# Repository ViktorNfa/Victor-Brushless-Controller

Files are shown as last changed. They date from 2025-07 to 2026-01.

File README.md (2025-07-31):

# Victor Brushless Controller (VBC)

This repository contains the **firmware** and **KiCad hardware design files** for the **Victor Brushless Controller (VBC)**, a custom BLDC motor controller inspired by the [Dagor Brushless Controller](https://github.com/byDagor/Dagor-Brushless-Controller).

## Overview

VBC is a compact, ESP32-based brushless controller designed for use in robotic and actuator applications. It integrates key hardware components to support precise control of brushless motors with wired or wireless communication.

The controller supports three operation modes:
- **Position control**.
- **Velocity control**.
- **Torque control**.

In both voltage- and current-control modes. It is compatible with the [SimpleFOC](https://docs.simplefoc.com/) library and can be programmed using the Arduino IDE.

## Features

- ESP32-based microcontroller.
- Onboard 3-phase MOSFET driver and half-bridges.
- Integrated 14-bit magnetic encoder.
- Current sensing resistors.
- Onboard temperature sensor.
- Custom firmware tailored for SimpleFOC.
- KiCad schematics and PCB layout included.

## Hardware Specs

| Specification | Value |
|---|---|
| Board Dimensions | ~44 x 44 mm |
| Supply Voltage | 5 – 24 V |
| Peak RMS Current | up to 40 A |
| Magnetic Sensor Resolution| 14 bits |
| Temperature Range | -10°C to 120°C |

> 🧪 Note: This is a **custom derivative project**, still under development. Use with caution and test thoroughly.

## Repository Structure

- `VBC-SW/` – Source code for the controller (Arduino + SimpleFOC).
- `VBC-HW/` – KiCad project files for PCB schematics and layout.
- `KiCad_libraries/` – Custom footprints & symbols needed for KiCad.

## Acknowledgements

Based on the fantastic work by [@byDagor](https://github.com/byDagor) and the [Dagor Brushless Controller](https://docs.dagor.dev/).

## License

To decide – see `...` file for details.

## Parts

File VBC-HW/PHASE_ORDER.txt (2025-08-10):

Dagor's connected Motor Phase Terminal C to DRV phase and amplifiers pins A and 1, respectively. 
Similarly, for Motor Phase Terminal A to DRV phase and amplifiers pins C and 3, respectively.

Not sure why he did this, maybe from his current motor setup or an error. 
It doesn't really affect anything as long as the BLDCDriver construct in the code is properly called reverted.

For my KiCad version I correctly connected A to A and C to C so no need to switch on the code.

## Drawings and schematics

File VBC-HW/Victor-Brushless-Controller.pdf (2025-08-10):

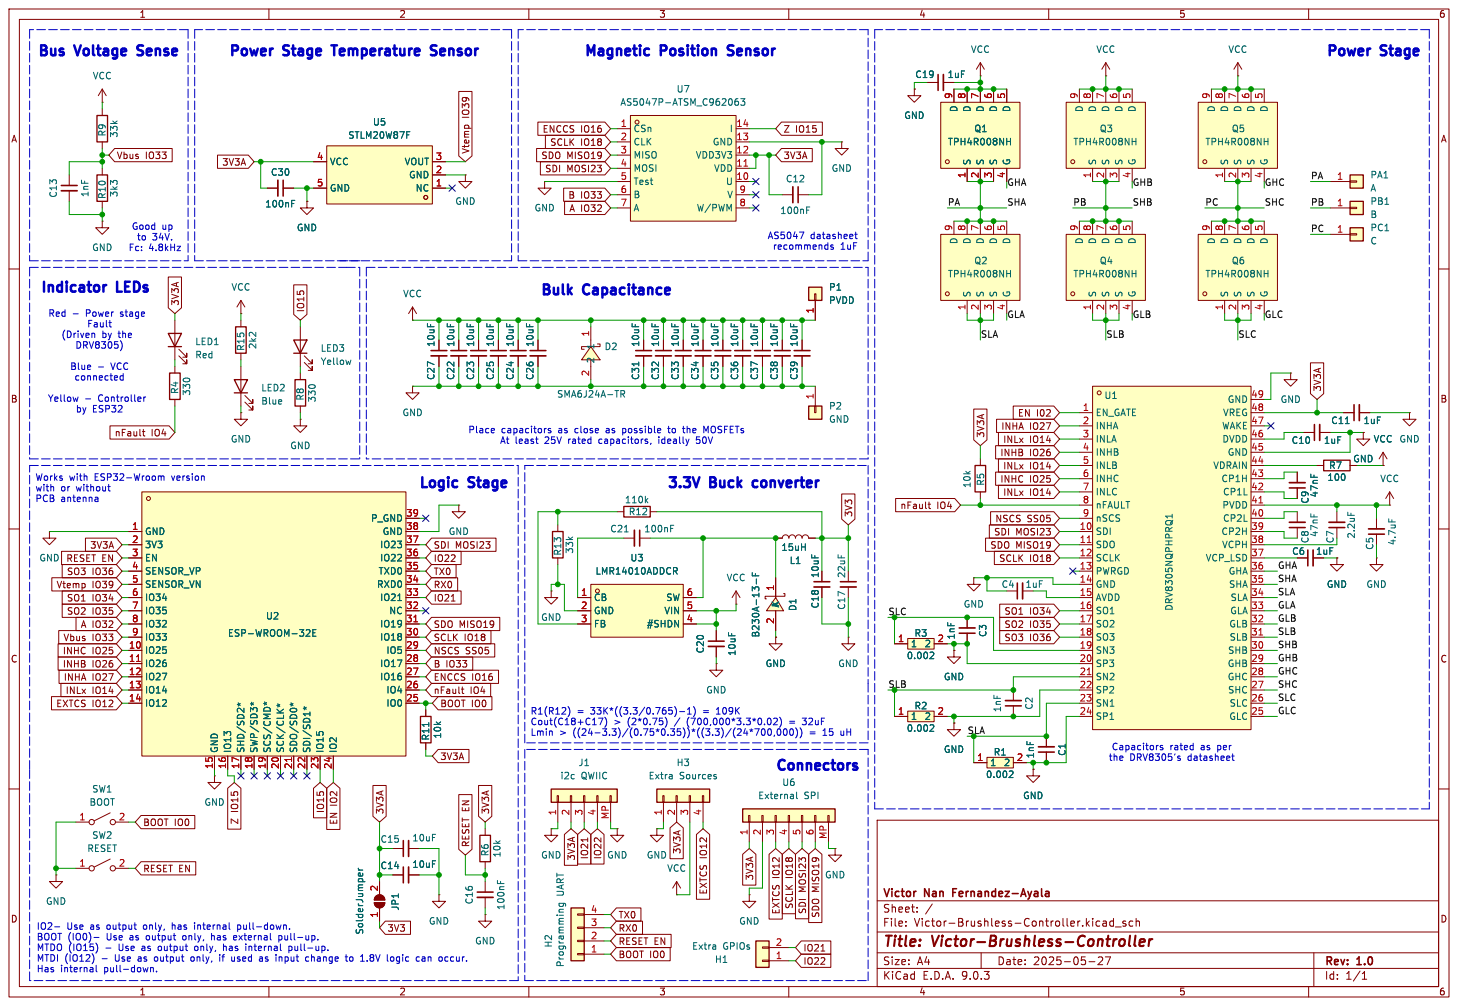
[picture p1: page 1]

9 W/PWM 8 U7 AS5047P-ATSM_C962063
CSn 1 CLK 2 MISO 3 MOSI 4 Test 5 B

connected Yellow - Controller by ESP32

2 D1 B230A-13-F C10 1uF GND GND GND C20 10uF GND GND

2 C20 10uF GND JP1 SolderJumper 1 2 U2 ESP-WROOM-32E GND 1

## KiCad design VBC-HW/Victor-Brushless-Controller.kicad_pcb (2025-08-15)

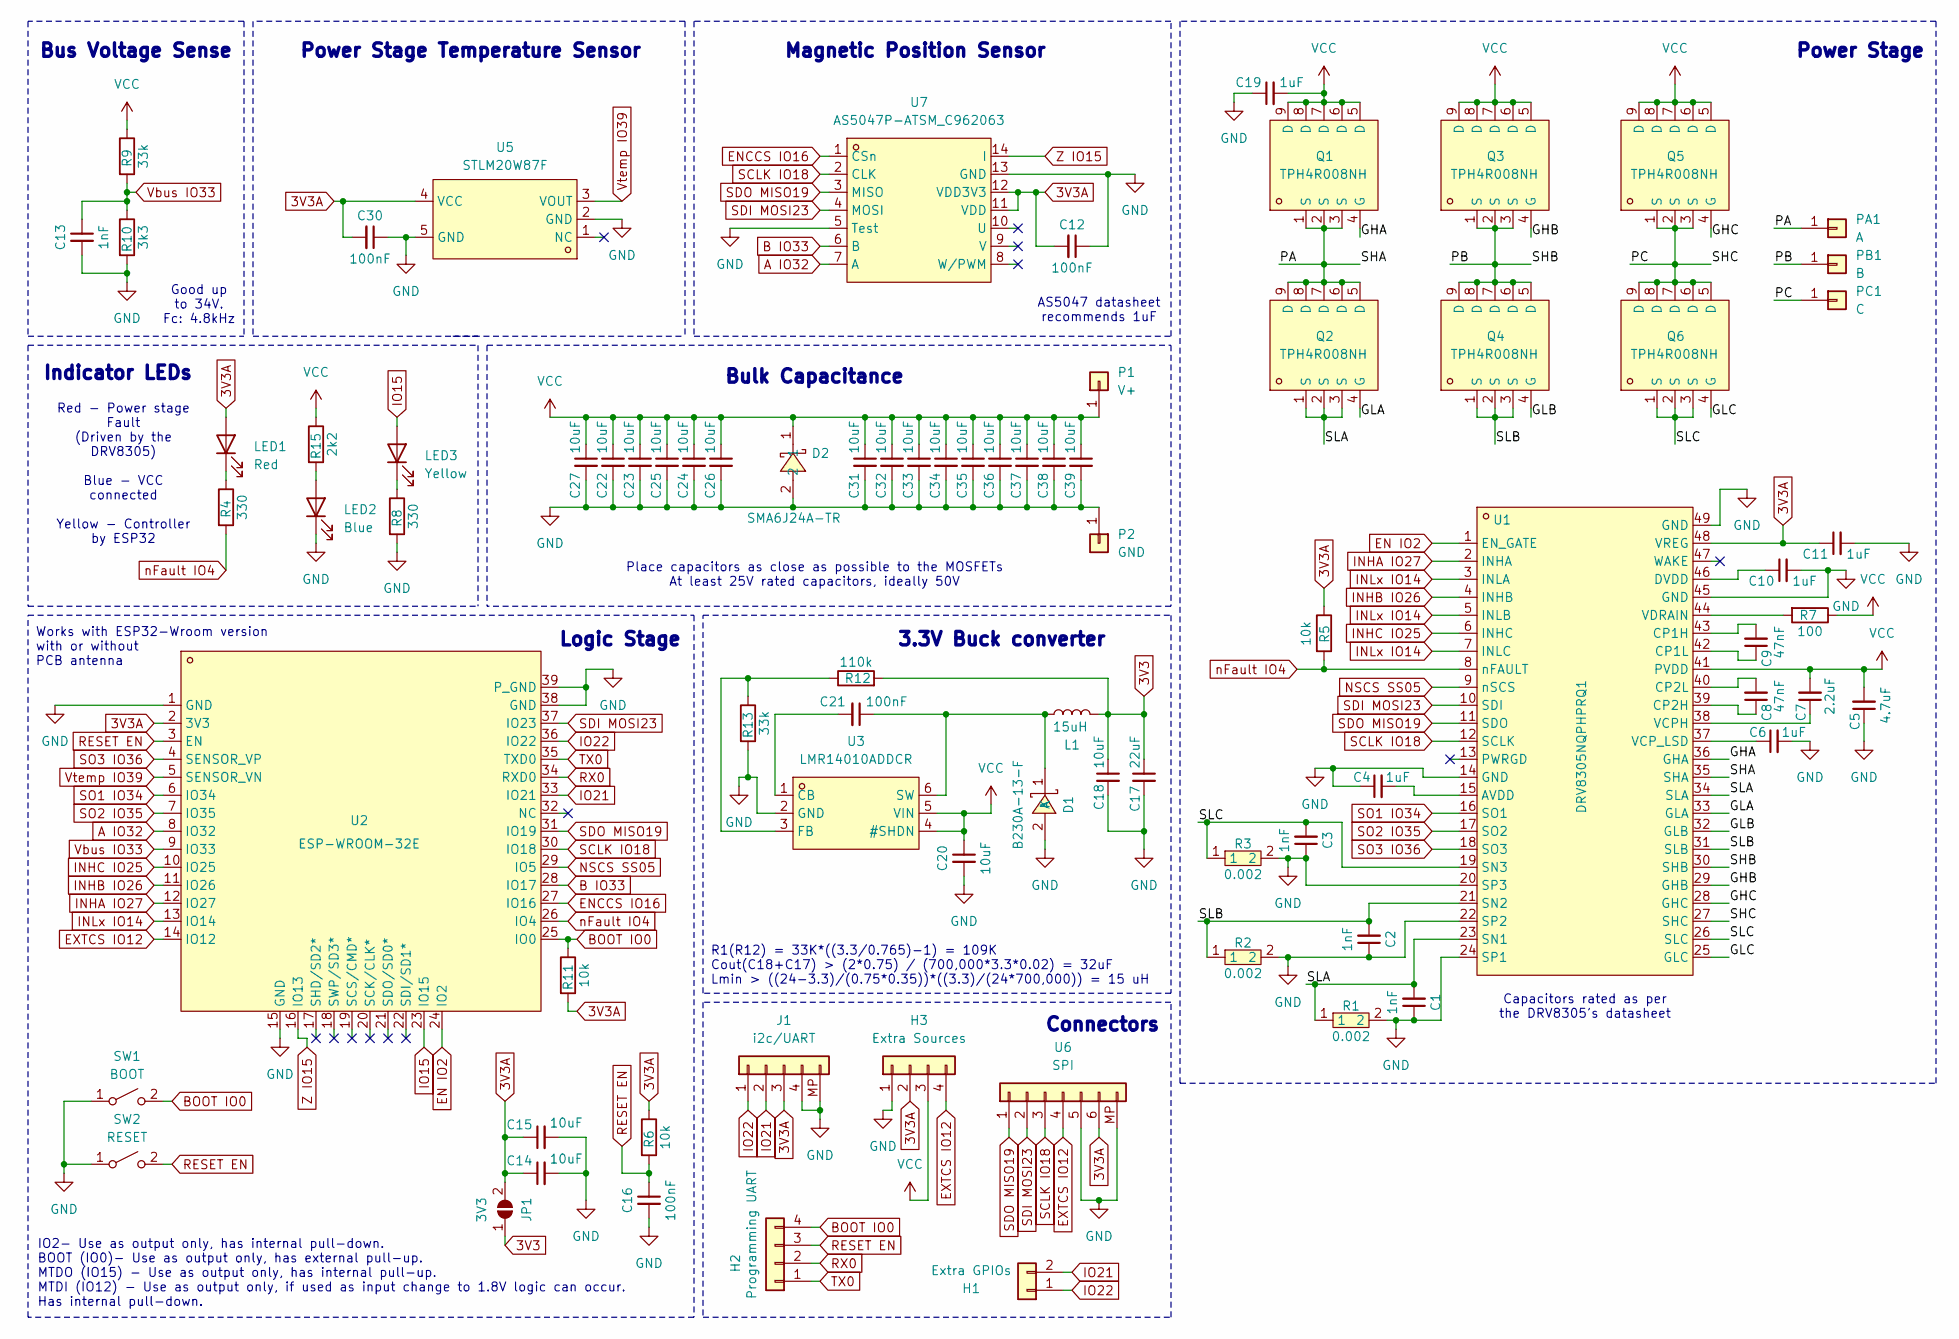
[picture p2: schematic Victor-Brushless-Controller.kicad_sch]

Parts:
C1, C2, C3, C13: 1nF; 0402B102K500NT
C4, C6, C10, C11: 1uF; CL05A105KA5NQNC
C5: 4.7uF; 1206B475K500NT
C7: 2.2uF; CL31B225KBHNNNE
C8: 47nF; CL21B473KCFNNNE
C9: 47nF; CL10B473KB8NNNC
C12, C16, C21, C30: 100nF; CL05B104KO5NNNC
C14: 10uF; CL05A106MQ5NUNC
C15: 10uF; CL05B104KO5NNNC
C17: 22uF; CL10A226MQ8NRNC
C18: 10uF; CL10A106MA8NRNC
C19: 1uF; CL10A105KB8NNNC
C20, C22, C23, C24, C25, C26, C27, C31, C32, C33, C34, C35, C36, C39: 10uF; GRM21BR61H106KE43L
C37, C38: 10uF; 1206X106M500NT
D1: B230A-13-F; LCSC Part C12889
D2: SMA6J24A-TR; SMA6J24A; LCSC Part C1975444
H1: Extra GPIOs; PinHeader_1x02_P2.54mm_Vertical
H2: Programming UART; PinHeader_1x04_P2.54mm_Vertical
H3: Extra Sources; PinHeader_1x04_P2.54mm_Vertical
J1: i2c/UART; JST_GH_BM04B-GHS-TBT_1x04-1MP_P1.25mm_Vertical
JP1: 3V3; SolderJumper-2_P1.3mm_Open_Pad1.0x1.5mm
L1: 15uH; PIS3D18P-150M-T
LED1: Red; KT-0603R
LED2: Blue; 19-217
LED3: Yellow; 19-213
P1: V+; Power_Connector
P2: GND; Power_Connector
PA1: A; BLDC_Connector
PB1: B; BLDC_Connector
PC1: C; BLDC_Connector
Q1, Q2, Q3, Q4, Q5, Q6: TPH4R008NH; TPH4R008NH,L1Q(M; LCSC Part C396039
R1, R2, R3: 0.002; CUM2512-24FR002; LCSC Part C323765
R4, R8: 330; 0402WGF3300TCE
R5, R6, R11: 10k; 0402WGF1002TCE
R7: 100; 0402WGF1000TCE
R9, R13: 33k; 0402WGF3302TCE
R10: 3k3; 0402WGF3301TCE
R12: 110k; RC0402FR-07110KL
R15: 2k2; 0402WGF2201TCE
SW1: BOOT; TS342A2P-WZ
SW2: RESET; TS342A2P-WZ
U1: DRV8305NQPHPRQ1; LCSC Part C701780
U2: ESP-WROOM-32E; LCSC Part C19949066
U3: LMR14010ADDCR; LCSC Part C388174
U5: STLM20W87F; LCSC Part C129796
U6: SPI; JST_GH_BM06B-GHS-TBT_1x06-1MP_P1.25mm_Vertical
U7: AS5047P-ATSM_C962063; AS5047P-ATSM; LCSC Part C962063

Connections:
3V3: C17.1, C18.1, JP1.1 (A), L1.2, R12.2
3V3A: C11.1, C12.2, C14.1, C15.1, C30.2, H3.2, J1.3, JP1.2 (B), LED1.2 (A), R5.1, R6.1, R11.2, U1.48 (VREG), U2.2 (3V3), U5.4 (VCC), U6.6, U7.11 (VDD), U7.12 (VDD3V3)
/GHA: Q1.4 (G), U1.36 (GHA)
/GHB: Q3.4 (G), U1.29 (GHB)
/GHC: Q5.4 (G), U1.28 (GHC)
/GLA: Q2.4 (G), U1.33 (GLA)
/GLB: Q4.4 (G), U1.32 (GLB)
/GLC: Q6.4 (G), U1.25 (GLC)
/PA: PA1.1, Q1.1 (S), Q1.2 (S), Q1.3 (S), Q2.5 (D), Q2.6 (D), Q2.7 (D), Q2.8 (D), Q2.9 (D), U1.35 (SHA)
/PB: PB1.1, Q3.1 (S), Q3.2 (S), Q3.3 (S), Q4.5 (D), Q4.6 (D), Q4.7 (D), Q4.8 (D), Q4.9 (D), U1.30 (SHB)
/PC: PC1.1, Q5.1 (S), Q5.2 (S), Q5.3 (S), Q6.5 (D), Q6.6 (D), Q6.7 (D), Q6.8 (D), Q6.9 (D), U1.27 (SHC)
/SLA: C1.2, Q2.1 (S), Q2.2 (S), Q2.3 (S), R1.1, U1.23 (SN1), U1.34 (SLA)
/SLB: C2.2, Q4.1 (S), Q4.2 (S), Q4.3 (S), R2.1, U1.21 (SN2), U1.31 (SLB)
/SLC: C3.2, Q6.1 (S), Q6.2 (S), Q6.3 (S), R3.1, U1.19 (SN3), U1.26 (SLC)
A IO32: U2.8 (IO32), U7.7 (A)
B IO33: U2.28 (IO17), U7.6 (B)
BOOT IO0: H2.4, R11.1, SW1.2 (B), U2.25 (IO0)
EN IO2: U1.1 (EN_GATE), U2.24 (IO2)
ENCCS IO16: U2.27 (IO16), U7.1 (CSn)
EXTCS IO12: H3.4, U2.14 (IO12), U6.4
GND: C1.1, C2.1, C3.1, C4.1, C5.1, C6.2, C10.2, C11.2, C12.1, C13.2, C14.2, C15.2, C16.2, C17.2, C18.2, C19.1, C20.2, C22.2, C23.2, C24.2, C25.2, C26.2, C27.2, C30.1, C31.2, C32.2, C33.2, C34.2, C35.2, C36.2, C37.2, C38.2, C39.2, D1.2 (A), D2.2, H3.1, J1.4, J1.MP, LED2.1 (K), P2.1, R1.2, R2.2, R3.2, R8.2, R10.2, R13.2, SW1.1 (A), SW2.1 (A), U1.14 (GND), U1.20 (SP3), U1.22 (SP2), U1.24 (SP1), U1.45 (GND), U1.49 (GND), U2.1 (GND), U2.15 (GND), U2.38 (GND), U2.39 (P_GND), U3.2 (GND), U5.2 (GND), U5.5 (GND), U6.5, U6.MP, U7.5 (Test), U7.13 (GND)
INHA IO27: U1.2 (INHA), U2.12 (IO27)
INHB IO26: U1.4 (INHB), U2.11 (IO26)
INHC IO25: U1.6 (INHC), U2.10 (IO25)
INLx IO14: U1.3 (INLA), U1.5 (INLB), U1.7 (INLC), U2.13 (IO14)
IO15: LED3.2 (A), U2.23 (IO15)
IO21: H1.2, J1.2, U2.33 (IO21)
IO22: H1.1, J1.1, U2.36 (IO22)
NSCS SS05: U1.9 (nSCS), U2.29 (IO5)
unnamed: C21.1, D1.1 (K), L1.1, U3.6 (SW)
unnamed: LED1.1 (K), R4.1
unnamed: LED2.2 (A), R15.2
unnamed: LED3.1 (K), R8.1
unnamed: C4.2, U1.15 (AVDD)
unnamed: C9.2, U1.43 (CP1H)
unnamed: C9.1, U1.42 (CP1L)
unnamed: C8.1, U1.39 (CP2H)
unnamed: C8.2, U1.40 (CP2L)
unnamed: C10.1, U1.46 (DVDD)
unnamed: C7.1, U1.38 (VCPH)
unnamed: C6.1, U1.37 (VCP_LSD)
unnamed: R7.2, U1.44 (VDRAIN)
unnamed: C21.2, U3.1 (CB)
unnamed: R12.1, R13.1, U3.3 (FB)
RESET EN: C16.1, H2.3, R6.2, SW2.2 (B), U2.3 (EN)
RX0: H2.2, U2.34 (RXD0)
SCLK IO18: U1.12 (SCLK), U2.30 (IO18), U6.3, U7.2 (CLK)
SDI MOSI23: U1.10 (SDI), U2.37 (IO23), U6.2, U7.4 (MOSI)
SDO MISO19: U1.11 (SDO), U2.31 (IO19), U6.1, U7.3 (MISO)
SO1 IO34: U1.16 (SO1), U2.6 (IO34)
SO2 IO35: U1.17 (SO2), U2.7 (IO35)
SO3 IO36: U1.18 (SO3), U2.4 (SENSOR_VP)
TX0: H2.1, U2.35 (TXD0)
VCC: C5.2, C7.2, C19.2, C20.1, C22.1, C23.1, C24.1, C25.1, C26.1, C27.1, C31.1, C32.1, C33.1, C34.1, C35.1, C36.1, C37.1, C38.1, C39.1, D2.1, H3.3, P1.1, Q1.5 (D), Q1.6 (D), Q1.7 (D), Q1.8 (D), Q1.9 (D), Q3.5 (D), Q3.6 (D), Q3.7 (D), Q3.8 (D), Q3.9 (D), Q5.5 (D), Q5.6 (D), Q5.7 (D), Q5.8 (D), Q5.9 (D), R7.1, R9.1, R15.1, U1.41 (PVDD), U3.4 (#SHDN), U3.5 (VIN)
Vbus IO33: C13.1, R9.2, R10.1, U2.9 (IO33)
Vtemp IO39: U2.5 (SENSOR_VN), U5.3 (VOUT)
Z IO15: U2.16 (IO13), U7.14 (I)
nFault IO4: R4.2, R5.2, U1.8 (nFAULT), U2.26 (IO4)

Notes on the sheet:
3.3V Buck converter
Red - Power stage Fault (Driven by the DRV8305) Blue - VCC connected Yellow - Controller by ESP32
Power Stage Temperature Sensor
Capacitors rated as per the DRV8305's datasheet
Indicator LEDs
Power Stage
AS5047 datasheet recommends 1uF
Place capacitors as close as possible to the MOSFETs At least 25V rated capacitors, ideally 50V
Works with ESP32-Wroom version with or without PCB antenna
Bus Voltage Sense
Good up to 34V. Fc: 4.8kHz
Bulk Capacitance
Connectors
Magnetic Position Sensor
R1(R12) = 33K*((3.3/0.765)-1) = 109K Cout(C18+C17) > (2*0.75) / (700,000*3.3*0.02) = 32uF Lmin > ((24-3.3)/(0.75*0.35))*((3.3)/(24*700,000)) = 15 uH
IO2- Use as output only, has internal pull-down. BOOT (IO0)- Use as output only, has external pull-up. MTDO (IO15) - Use as output only, has internal pull-up. MTDI (IO12) - Use as output only, if used as input change to 1.8V logic can occur. Has internal pull-down.
Logic Stage

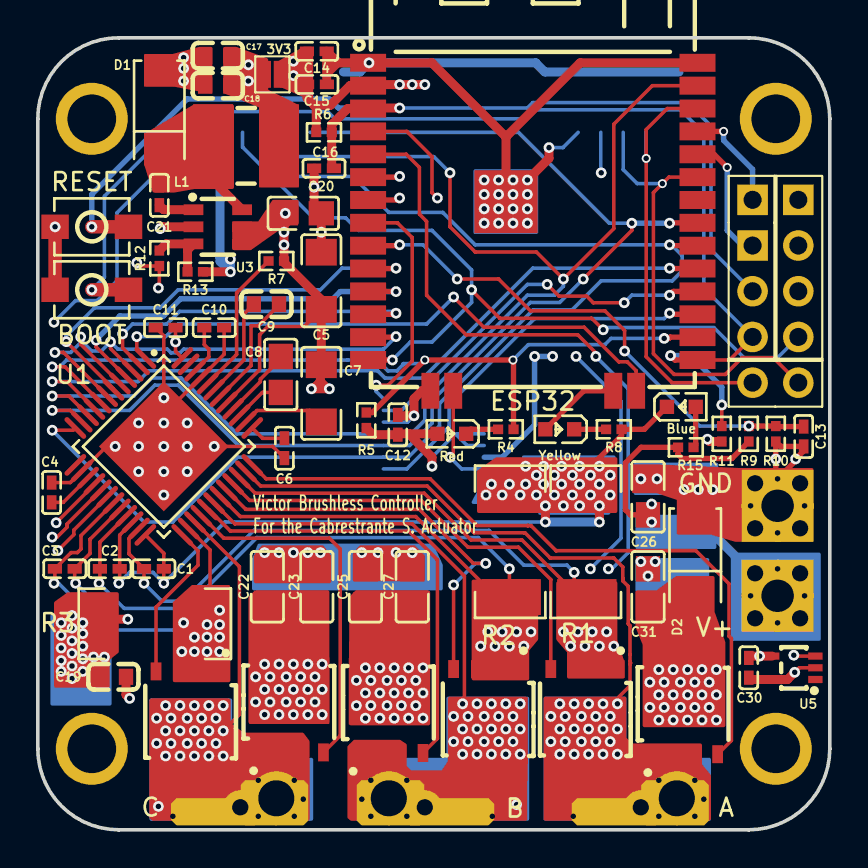
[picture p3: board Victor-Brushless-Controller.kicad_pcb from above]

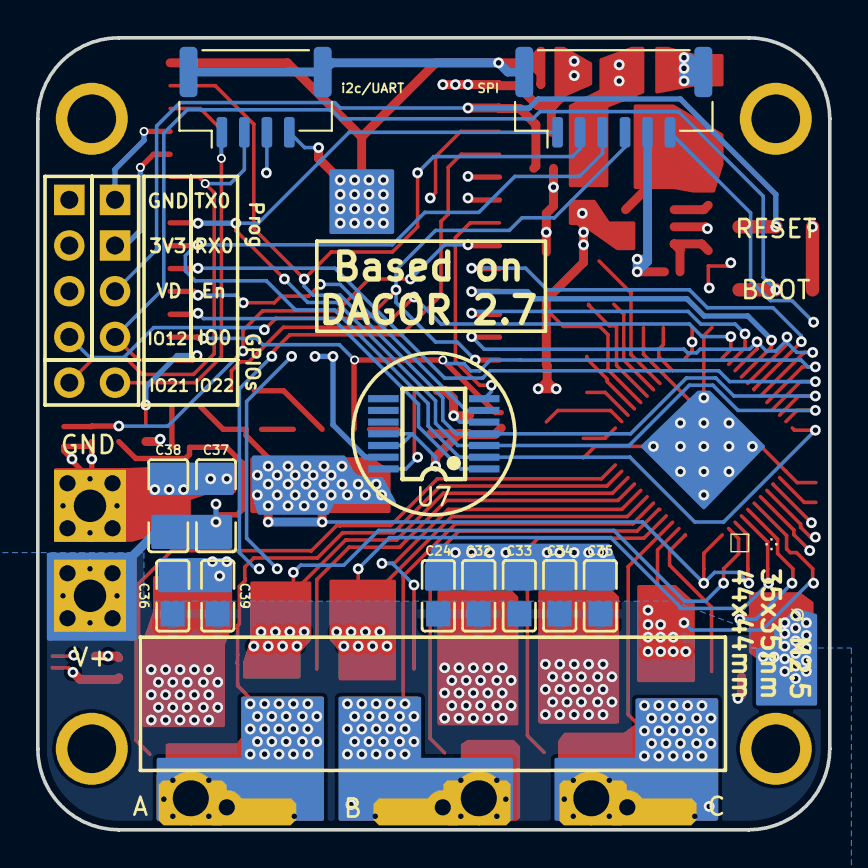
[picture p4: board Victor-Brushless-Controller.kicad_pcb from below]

Board: 4 copper layers, 44.0 x 44.0 mm, 81 parts (13 on the bottom side), 58 nets.

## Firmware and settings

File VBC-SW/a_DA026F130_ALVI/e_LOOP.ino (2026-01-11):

//###########################################
//         SUPER LOOP - Core 1
//###########################################

// Do NOT add delay inside the loop void.

void loop() {

  if (state_machine < DRV_WARNING){
     // These functions have to run as fast as possible
    motor.loopFOC();
    autoSweepUpdate();
    motor.move();
    activeComp();

    if (print_foc_freq) printFOCfreq();

    #ifdef DEBUG_ADAPTER
      command.run();
      //motor.monitor();
    #endif 

  } else{

    static bool error_printed = false;

    if (!error_printed){
      error_printed = true;
      Serial.print("Dagor: Error -> State Machine: ");
      Serial.println(state_machine);
    }
    vTaskDelay(1 / portTICK_PERIOD_MS);

  }

}

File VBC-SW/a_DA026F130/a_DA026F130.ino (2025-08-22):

//####################################################################################
//                         Dagor Controller Alpha Firmware
//                   Compatible with Alpha versions 2.4 and above
//            [Modified by Victor Nan Fernandez-Ayala for the VBC board]
//####################################################################################

#include <SimpleFOC.h>
#define FW_VERSION "1.4.0"

// The firmware is separated into 7 tabs (a - g), make sure all files are stored in the folder with the same name as tab a_DAXXXFXXX.
// This tab cointains the parameters to customize the controller. Learn more at https://docs.dagor.dev/

// Refactoring to use both cores leveraging freeRTOS
//TODO:
//    Stall detection algorithm
//    Finish RS-485-based protocol, directional comms working
//    Virtual Walls algo
//    Detect DRV warnings vs. errors
//    Make nicer out of bounds behavior
//    Finish implementing state machine
//    Change "H" homing command to accept home as arbitrary number or current position

//#######_USER SET-UP PARAMETERS_#######
#define ACT_ID 100                                              // Actuator ID, used for ESP-NOW or RS-485 comms
const int pp = 20;                                              // BLDC motor number of pole pairs
const float phaseRes = 0.186;                                   // Phase winding resistance [ohms]
const float amp_limit = 7.0;                                   // IQ current limit [amps] - requires trueTorque mode                           
const float alignStrength = 0.1;                                // Percentage of available bus voltage used to calibrate the sensor on start-up
MotionControlType controlType = MotionControlType::torque;      // control types: angle, velocity, torque


// Below are the control loops start-up parameters, to obtain the desired response out of the  
// controller they need to be tuned. These parameters can be tuned via the SimpleFOC's "Commander"  
// interface, which is based on ASCII character command ids. There are two types of commands, a 
// fetch and a set. A fetch command will have the following structure:
//                               motor ID ->  MLC <- Current
//                                             ^
//                                             |
//                                           Limits
//
// These commands can be sent through the Serial Monitor, make sure to set the baud rate to 115200 and 
// "Newline". To the right of the variables below there are the characters that would be used to fetch
// or set each individual parameter. There is a cheat-sheet of the commands at the bottom of this tab.
// Make sure to write the final values of the parameters after tuning to update the firmware and 
// upload it again.


//#######_START-UP CONTROLLER PARAMETERS_#######                                         //  Commander IDs:
const float cp = 0.5;                     // QD current loops PROPORTONAL gain value            - MQP & MDP
const float ci = 20.0;                    // QD current loops INTEGRAL gain value                - MQI & MDI
const float cd = 0.0;                     // QD current loops DERIVATIVE gain value             - MQD & MDD
const float lpQDFilter = 0.01;            // QD current loops measurement low-pass filter       - QF & DF

const float vp = 0.3;                     // Velocity control loop PROPORTIONAL gain value      - VP
const float vi = 2.0;                     // Velocity control loop INTEGRAL gain value          - VI
const float vd = 0.0;                     // Velocity control loop DERIVATIVE gain value        - VD
const float lpVelFilter = 0.01;           // Velocity measurement low-pass filter               - VF
const float velocity_limit = 20;          // Velocity limit [rad/s]                             - LV

const float ap = 30.0;                    // Position control loop PROPORTIONAL gain value      - AP
const float ai = 0.0;                     // Position control loop INTEGRAL gain value          - AI
const float ad = 0.0;                     // Position control loop DERIVATIVE gain value        - AD
const float lpPosFilter = 0.001;          // Position measurment low-pass filter                - AF
const float voltageRamp = 2000;           // Change in voltage allowed [Volts per sec]          - VR


//########_ADVANCED PARAMETERS_##########
#define CURRENT_SENSE                     // Define if using current sense, difference between current control or voltage control mode.  
const bool trueTorque = true;             // Even if using current sense, torque mode can be voltage torque mode if set to false
const bool print_currents = true;         // Monitor currents through the serial terminal 
const bool print_dq_currents = true;      // true-> print DQ currents, false -> print phase currents

#define MONITOR_TEMP                      // define -> monitor and evaluate controllers temperature, parameters below ignored if undef
const bool print_temp = false;            // Monitor temperature through the serial terminal
const int maxTemp = 75;                   // Maximum operating temperature of the power-stage [°C]
const float overTempTime = 1.0;           // Time to elapse in an over-temperature state to disable the controller [seconds]

#undef MONITOR_BUS_VOLTAGE                // Monitor bus voltage, automatically adjust to the lowering battery voltage
const bool print_bus_voltage = false;     // Monitor the bus voltage through the serial terminal
const float voltageOverride = 22.0;       // Voltage of your power source [Volts], overrides source voltage if MONITOR_BUS_VOLTAGE is undefined

#define MONITOR_ROTOR                     // Monitor rotor position and velocity, parameters below ignored if undef
const bool print_rotor_data = false;      // Monitor roto's position and velocity (respectively) through the serial terminal
const float max_rotor_position = 10000;   // Max position [rad] the rotor is allowed to spin to; above this value, motor will freewheel 
const float min_rotor_position = -10000;  // Min position [rad] the rotor is allowed to spin to; below this value, motor will freewheel 

#undef SKIP_SENSOR_CALIB                  // Skip the position sensor calibration on start-up
                                          // electric angle offset and natural direction printed on start-up
const float zero_elec_angle = 0.00;       // Printed as: "MOT: Zero elec. angle: X.XX"
Direction nat_dir = Direction::CW;        // Can be either CW or CCW

#define DEBUG_ADAPTER                     // define if using USB programming/debug adapter (usb to ttl connected to board)
                                          // Recommended to disable when adapter will not be connected to computer
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

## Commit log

2025-03-29 Added KiCad libraries
    [Victor-Brushless-Controller.kicad_pcb, Victor-Brushless-Controller.kicad_sch]
2025-04-01 Finished Power Stage schematic
    [Victor-Brushless-Controller.kicad_pcb, Victor-Brushless-Controller.kicad_sch]
2025-05-23 Added Kicad schematic magnetic, bus and temp
    [Victor-Brushless-Controller.kicad_sch]
2025-05-26 Added buck converter
    [Victor-Brushless-Controller.kicad_sch]
2025-05-26 Finished schematics connections
    [Victor-Brushless-Controller.kicad_sch, untitled.kicad_sch]
2025-05-26 Cleaned up schematic
    [untitled.kicad_sch]
2025-05-27 Started adding footprints
    [Victor-Brushless-Controller.kicad_sch]
2025-06-03 Added footprints to project
2025-06-05 Added footprints to schematic
    [Victor-Brushless-Controller.kicad_sch]
2025-06-12 Assigned external connectors
    [Victor-Brushless-Controller.kicad_sch]
2025-06-12 Finished assigning and creating all footprints
    [Victor-Brushless-Controller.kicad_sch]
2025-06-12 Ready to tetris
    [Victor-Brushless-Controller.kicad_pcb, Victor-Brushless-Controller.kicad_sch]
2025-06-14 Preliminary component placing
    [Victor-Brushless-Controller.kicad_pcb, Victor-Brushless-Controller.kicad_sch]
2025-06-14 PCB starting to take shape
    [Victor-Brushless-Controller.kicad_pcb]
2025-06-21 Updated PCB and code
    [Victor-Brushless-Controller.kicad_pcb, Victor-Brushless-Controller.kicad_sch]
2025-06-21 Added test codes for magnetic sensor
2025-06-24 Working with smaller GM3506 motor
2025-06-25 Updates connections in board
    [Victor-Brushless-Controller.kicad_pcb, Victor-Brushless-Controller.kicad_sch]
2025-07-11 Fix closed loop control
    [a_DA026F130.ino, c_SIMPLEFOC.ino, closed_loop_control.ino]
2025-07-12 Added init current sense
2025-07-14 Added current closed loop control test
2025-07-14 Fix current control
2025-07-16 Fixed basic current sense
    [current_closed_loop.ino, current_sense.ino, g_TASKS.ino]
2025-07-18 Working clean up of current control
2025-07-19 Added tests for LA8308 motor
2025-07-20 Big motor working
2025-07-29 Added temperature sensor
2025-07-30 Might be wrong, just saving for history
    [a_DA026F130_WP.ino, d_SETUP.ino, f_SETUP_FUNCTIONS.ino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]
2025-07-30 Revert "Might be wrong, just saving for history"
    This reverts commit cdf17d161a2acca385215cf7318953e3e6c9fc40.
    [a_DA026F130_WP.ino, d_SETUP.ino, f_SETUP_FUNCTIONS.ino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]
2025-07-30 Final save for bar torque setup
2025-08-10 Starting added traces to board
    [Victor-Brushless-Controller.kicad_pcb, Victor-Brushless-Controller.kicad_sch]
2025-08-11 Finished top layer connections
    [Victor-Brushless-Controller.kicad_pcb]
2025-08-13 Finished vias and Inner layer 1
    [Victor-Brushless-Controller.kicad_pcb, Victor-Brushless-Controller.kicad_sch]
2025-08-14 Started finishing vias conencting in top later
    [Victor-Brushless-Controller.kicad_pcb]
2025-08-15 Finished all connections
    [Victor-Brushless-Controller.kicad_pcb, Victor-Brushless-Controller.kicad_sch]
2025-08-15 Fully finished board
    [Victor-Brushless-Controller.kicad_pcb]
2025-08-22 Cleanup some code for basic version of big motor no load
2025-08-22 Final runed version of big motor
2026-01-05 Added cody ready for fatigue test of actuator
2026-01-11 Fix code issues for Alvi test
    [a_DA026F130_ALVI.ino, e_LOOP.ino, f_SETUP_FUNCTIONS.ino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]
